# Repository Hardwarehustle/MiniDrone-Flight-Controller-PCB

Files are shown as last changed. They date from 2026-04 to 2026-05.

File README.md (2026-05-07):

#  MiniDrone Flight Controller PCB
## Project Overview

This is a fully integrated **mini quadcopter flight controller PCB** shaped as a drone frame — the PCB itself acts as the structural frame with four motor mount arms extending from the central compute hub. It packs an **ESP32-S3** SoC (dual-core 240 MHz Xtensa LX7, Wi-Fi + BLE 5.0), an **OV2640 camera** (24-pin FPC), a **MPU-6050 IMU** (6-axis gyro + accelerometer), **LiPo battery management** (TP4056 + DW01A + FS8205A), **4× SI2302A N-MOSFET brushed motor drives**, a **microSD card** slot for SD_MMC, and **USB-C OTG** — all on a single X-shaped blue PCB.

The board is designed for a compact indoor FPV or autonomous mini-drone platform with onboard vision, motion sensing, Wi-Fi/BLE telemetry, and local SD logging.

---

##  Project Visuals

### Schematic
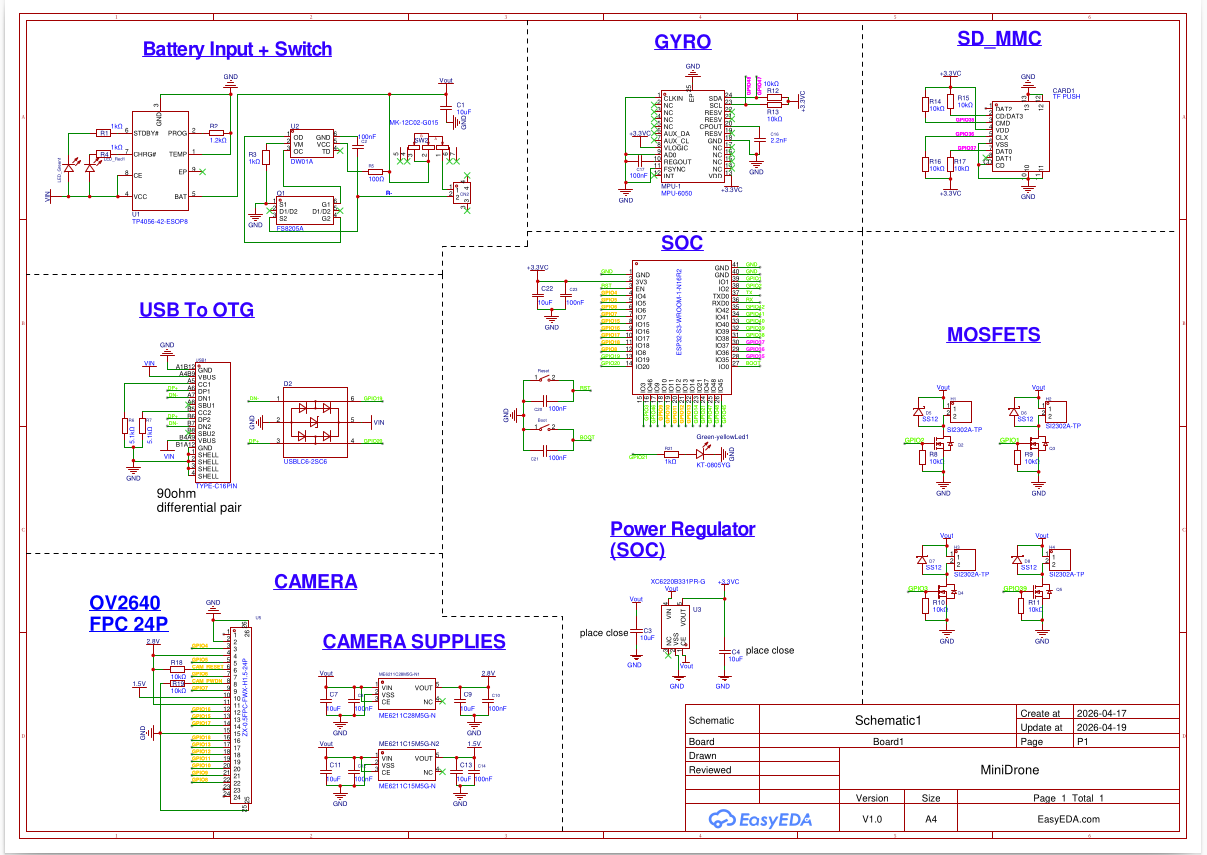
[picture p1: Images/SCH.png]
Schematic


### PCB Layout
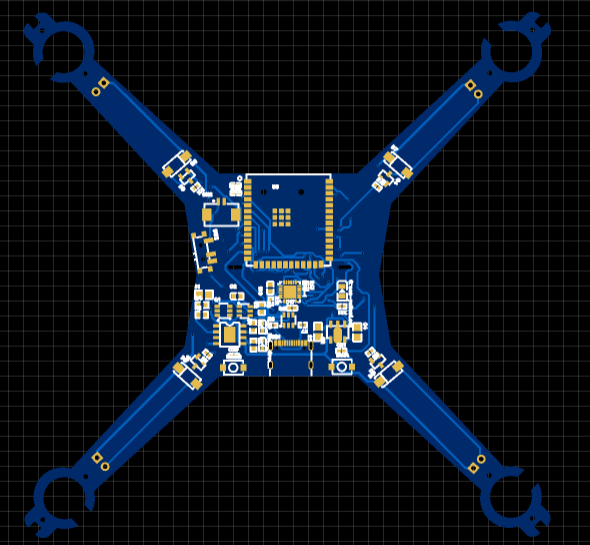
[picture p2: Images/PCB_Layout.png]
PCB Layout


### 3D Board Top View
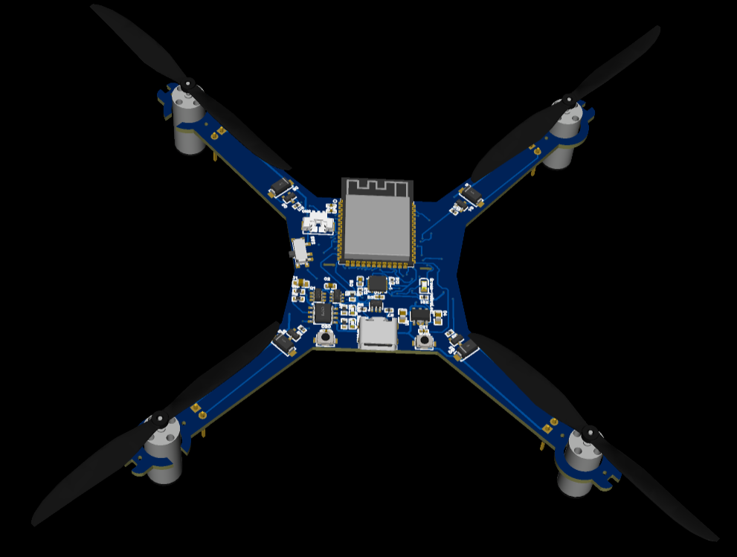
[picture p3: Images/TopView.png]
3D Top View


### 3D Board Bottom View
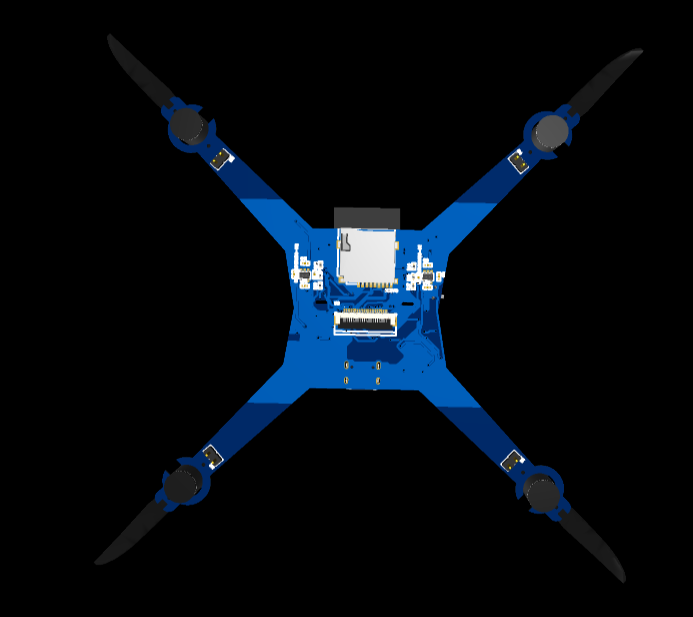
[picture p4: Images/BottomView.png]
3D Bottom View

---

##  System Architecture

```
LiPo Battery ──► MK-12C02 Slide Switch (SW2)
                          │
               TP4056 (U1) Li-ion Charger ◄── USB-C VBUS (charging)
                          │
               DW01A (U2) Battery Protection (OC, OD, TD)
                          │
               FS8205A (Q1) Dual P-MOSFET Protection Switch
                          │
                       Vout Rail
                          │
          ┌───────────────┼───────────────────────────┐
          ▼               ▼                           ▼
  XC6220B331 LDO    ME6211C28 LDO (2.8V)   ME6211C15 LDO (1.5V)
  (+3.3V for SoC)   (OV2640 DVDD/AVDD)     (OV2640 core)
          │
       +3.3VC Rail
          │
   ┌──────┼──────────────────────────────────────┐
   ▼      ▼              ▼           ▼           ▼
ESP32-S3  MPU-6050     SD_MMC     USB-C OTG   SI2302A×4
(SoC)   (Gyro/Accel)  (CARD1)   (TYPE-C16P)  (Motors H1-H4)
   │
   └──► OV2640 Camera (24P FPC, U5)
```

---

##  Component BOM

### Core ICs

| Ref | Part | Function |
|:---:|:---|:---|
| ESP32-S3-WROOM-1-N16R2 | ESP32-S3 SoC | Dual-core 240 MHz, Wi-Fi + BLE 5.0, 16MB Flash, 2MB PSRAM |
| U1 | TP4056-42-ESOP8 | 1A Li-ion/LiPo battery charger |
| U2 | DW01A | Battery protection IC (OC / OD / short circuit) |
| Q1 | FS8205A | Dual N-MOSFET battery protection switch |
| U3 | XC6220B331PR-G | 300mA LDO regulator — Vout → +3.3V |
| ME6211C28M5G-N1 | ME6211C28 | 300mA LDO — 2.8V for OV2640 |
| ME6211C15M5G-N2 | ME6211C15 | 300mA LDO — 1.5V for OV2640 core |
| MPU-1 | MPU-6050 | 6-axis IMU (3-axis gyro + 3-axis accel), I2C |
| U5 | ZX-0.5FPC-FWX-H1.5-24P | OV2640 camera 24-pin FPC connector |
| CARD1 | TF PUSH | MicroSD card (SD_MMC 4-bit interface) |
| USB1 | TYPE-C 16PIN | USB-C OTG connector |
| D2 | USBLC6-2SC6 | USB ESD protection TVS |

### Motor Drive MOSFETs

| Ref | Part | GPIO | Motor |
|:---:|:---:|:---:|:---:|
| Q2 | SI2302A-TP | GPIO2 | Motor H1 (Front-Left) |
| Q3 | SI2302A-TP | GPIO1 | Motor H2 (Front-Right) |
| Q4 | SI2302A-TP | GPIO3 | Motor H3 (Rear-Left) |
| Q5 | SI2302A-TP | GPIO39 | Motor H4 (Rear-Right) |

Each SI2302A N-MOSFET gate is driven directly from ESP32-S3 PWM GPIO through a 10kΩ gate resistor, and is protected by an SS12 Schottky flyback diode (D5–D8).

---

##  ESP32-S3 GPIO Assignment

| GPIO | Signal | Block |
|:---:|:---|:---|
| GPIO1 | Motor H2 (PWM) | MOSFET Q3 |
| GPIO2 | Motor H1 (PWM) | MOSFET Q2 |
| GPIO3 | Motor H3 (PWM) | MOSFET Q4 |
| GPIO39 | Motor H4 (PWM) | MOSFET Q5 |
| GPIO4 | CAM_XCLK | OV2640 Clock |
| GPIO5 | CAM_VSYNC | OV2640 |
| GPIO6 | CAM_RESET | OV2640 |
| GPIO7 | CAM_PWDN | OV2640 Power Down |
| GPIO8–GPIO18 | CAM_D0–D7, PCLK, HREF, SIOC, SIOD | OV2640 data + I2C |
| GPIO19 | USB D+ | USB OTG |
| GPIO20 | USB D− | USB OTG |
| GPIO21 | Status LED | Green-yellow LED |
| GPIO35 | SD_CMD | SD_MMC |
| GPIO36 | SD_CLK | SD_MMC |
| GPIO37 | SD_DAT0 | SD_MMC |
| GPIO47 | MPU-6050 SCL | I2C |
| GPIO48 | MPU-6050 SDA | I2C |
| GPIO0 | BOOT | Boot mode select |
| EN | RESET | Hardware reset |

---

##  Battery Management System

The BMS consists of three stages working together to safely charge and discharge the LiPo cell:

### Stage 1 — Charging: TP4056
- Max charge current: **1A** (set by PROG pin resistor R2 = 1.2kΩ)
- Charge voltage: **4.2V** (fixed internal reference)
- Charging via USB-C VBUS
- CHRG# pin drives **LED_Red** (charging indicator)
- STDBY# pin drives **LED_Green** (charge complete)

### Stage 2 — Protection: DW01A
- Overcurrent protection (OC)
- Over-discharge protection (OD): cuts off battery below ~2.4V
- Short circuit protection (TD)
- Operates with external dual MOSFET (FS8205A)

### Stage 3 — Switching: FS8205A
- Dual N-channel MOSFET in a single SOT-23-6 package
- G1 controlled by OD pin of DW01A
- G2 controlled by OC pin of DW01A
- Both protect battery from damage during abnormal conditions

---

##  OV2640 Camera Interface

The OV2640 is a 2MP image sensor from OmniVision, connected via a **24-pin 0.5mm pitch FPC connector** (ZX-0.5FPC-FWX-H1.5-24P, U5). It requires three regulated power supplies generated by dedicated ME6211 LDOs:

| Rail | Voltage | LDO | Purpose |
|:---:|:---:|:---:|:---|
| AVDD / DOVDD | 2.8V | ME6211C28M5G-N1 | Analog + I/O power |
| DVDD | 1.5V | ME6211C15M5G-N2 | Digital core power |

Camera control pins from ESP32-S3:
- **CAM_RESET** (GPIO6) — hardware reset
- **CAM_PWDN** (GPIO7) — power down mode
- **SIOC/SIOD** — I2C configuration bus (SCCB protocol)
- **GPIO4–GPIO18** — parallel DVP data bus (D0–D7, PCLK, VSYNC, HREF)

---

##  MPU-6050 IMU (Gyro + Accel)

The **MPU-6050** is a 6-axis MEMS IMU providing 3-axis gyroscope and 3-axis accelerometer data over I2C at up to 400 kHz. It is connected to:
- **SDA → GPIO48**, **SCL → GPIO47**
- I2C pull-ups R12 and R13 (10kΩ each) to +3.3VC
- INT pin available for interrupt-driven data-ready notification
- FSYNC pin available for frame sync with camera
- Decoupling: C16 (2.2nF) + C17 (100nF) on VDD

The MPU-6050 data feeds the flight stabilization loop running on the ESP32-S3 for attitude control (roll, pitch, yaw).

---

##  MicroSD Card (SD_MMC)

The microSD card (CARD1 — TF PUSH type) operates in **SD_MMC 4-bit wide bus mode** for high-speed data logging:

| Signal | GPIO | Description |
|:---:|:---:|:---|
| SD_CMD | GPIO35 | Command line |
| SD_CLK | GPIO36 | Clock |
| SD_DAT0 | GPIO37 | Data bit 0 |

Pull-up resistors R14–R17 (10kΩ) hold all SD_MMC lines high when idle.

---

##  USB-C OTG

The **TYPE-C 16-pin connector** (USB1) supports:
- **USB 2.0 Full-Speed** native on ESP32-S3 (GPIO19/GPIO20 as D+/D−, 90Ω differential pair)
- **OTG** capability — can act as USB device or host
- CC1/CC2 lines with R6/R7 (5.1kΩ) for USB-C cable orientation and current advertisement
- **USBLC6-2SC6 TVS array (D2)** for full ESD protection on DP/DM lines
- VBUS routing for charging input to TP4056

---

##  Auto-Reset and Boot Circuit

| Signal | GPIO | Component | Function |
|:---:|:---:|:---:|:---|
| RST | EN | C20 (100nF) | Reset filter capacitor |
| BOOT | GPIO0 | C21 (100nF) | Boot mode filter cap |
| RST | — | RESET button | Manual reset |
| BOOT | — | BOOT button | Manual boot mode entry |
| GPIO21 | — | Green-yellow LED (KT-0805YG) + R21 1kΩ | Status indicator |

---

##  Power Architecture Summary

```
USB-C VBUS (5V) ──► TP4056 charger ──► LiPo Battery (3.7V)
                                              │
                                        DW01A + FS8205A
                                              │
                                           Vout
                          ┌───────────────────┼────────────────────┐
                          ▼                   ▼                    ▼
                  XC6220B331 LDO       ME6211C28 (2.8V)    ME6211C15 (1.5V)
                   → +3.3V              → OV2640 AVDD         → OV2640 DVDD
                   ESP32-S3
                   MPU-6050
                   SD Card
                          │
                  4× SI2302A → Brushed Motors (direct Vout)
```

---

##  PCB Design Highlights

- **Tool:** EasyEDA V1.0
- **Board shape:** X-frame quadcopter — PCB is simultaneously the structural drone frame
- **Arm ends:** 4× motor mount clamps (H1–H4) at arm tips
- **Center hub:** ESP32-S3, camera FPC, MPU-6050, SD card, USB-C all centrally placed
- **Color:** Blue PCB with gold pads (ENIG finish recommended)
- **Layers:** 2-layer
- **USB differential pair:** Routed as 90Ω controlled impedance

---

##  Bring-Up Procedure

### Step 1 — Power Check
- Connect LiPo battery and slide SW2 to ON
- Measure Vout (3.5–4.2V), +3.3V at ESP32 VDD, 2.8V at OV2640, 1.5V at OV2640 DVDD

### Step 2 — USB and Programming
- Connect USB-C to PC
- Press BOOT + RESET (or use auto-reset via DTR/RTS if host-side bridge added)
- Flash firmware using ESP-IDF or Arduino IDE (ESP32-S3 target)

### Step 3 — IMU Test
- I2C scan on GPIO47/GPIO48 — expect MPU-6050 at address 0x68
- Read accel and gyro registers — verify non-zero output when board is tilted

### Step 4 — Camera Test
- Enable OV2640 power (ME6211 CE pins asserted)
- Init SCCB (I2C) to configure OV2640 registers
- Read a JPEG frame — verify image over Wi-Fi or SD

### Step 5 — SD Card Test
- Mount FAT32 SD card
- Write a test log file — verify read-back

### Step 6 — Motor Test
- Apply PWM to GPIO1–GPIO3 and GPIO39 at low duty (5–10%)
- Verify each SI2302A gate toggles correctly with oscilloscope
- Verify motor spins at low throttle safely

---

##  Design Notes & Cautions

- **SI2302A gate voltage** — ESP32-S3 GPIO drives 3.3V; SI2302A Vgs(th) ≈ 0.9V min, ensure full enhancement at 3.3V drive
- **SS12 flyback diodes (D5–D8)** — essential for brushed motor inductive kickback protection; place close to MOSFET drain
- **OV2640 power sequence** — apply 2.8V before 1.5V per OV2640 datasheet power-up sequence
- **90Ω USB differential pair** — GPIO19/GPIO20 traces must be routed as a matched-impedance differential pair; keep equal length and spacing
- **MPU-6050 placement** — mount at the board center of mass for accurate attitude measurement; avoid placing near switching regulators
- **TP4056 PROG resistor (R2 = 1.2kΩ)** — sets charge current to ~1A; verify LiPo cell can handle this charge rate (1C minimum rated capacity)
- **PCB-as-frame structural note** — board is structural; use FR4 1.6mm minimum thickness; motor clamp holes should be reinforced with copper rings

---

## License

This project is open for educational and personal use.  
© 2026 Janardhan BV — All rights reserved.

---

## Author

**Janardhan BV**  
Embedded Hardware Engineer | PCB Design | Robotics  
Bengaluru, India

---
*MiniDrone — ESP32-S3 Flight Controller PCB | Designed in EasyEDA*

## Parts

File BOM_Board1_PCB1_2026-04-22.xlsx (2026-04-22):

No. | Quantity | Comment | Designator | Footprint | Value | Manufacturer Part | Manufacturer | Supplier Part | Supplier
1 | 2 | TS-1088R-02026 | Boot,Reset | SW-SMD_L3.9-W3.0-P4.45 |  | TS-1088R-02026 | XUNPU(讯普) | C455280 | LCSC
2 | 3 | 10uF | C1,C3,C4 | C0805 | 10uF | CL10A106MQ8NNNC | SAMSUNG(三星) | C1691 | LCSC
3 | 1 | 100nF | C2 | C0603 | 100nF | 0603B104K250CT | Walsin(华新科) | C83054 | LCSC
4 | 5 | 10uF | C7,C9,C11,C13,C22 | C0402 | 10uF | CL10A106MQ8NNNC | SAMSUNG(三星) | C1691 | LCSC
5 | 8 | 100nF | C8,C10,C12,C14,C17,C20,C21,C23 | C0402 | 100nF | CC0402KRX7R7BB104 | YAGEO(国巨) | C60474 | LCSC
6 | 1 | 2.2nF | C16 | C0603 | 2.2nF | 0603B222K500CT | Walsin(华新科) | C93190 | LCSC
7 | 1 | TF PUSH | CARD1 | TF-SMD_TF-PUSH |  | TF PUSH | SHOU HAN(首韩) | C393941 | LCSC
8 | 1 | AFC12-S02DCC-00 | CN2 | CONN-SMD_AFC12-S02DCC-00 |  | AFC12-S02DCC-00 | JS(钜硕电子) | C395328 | LCSC
9 | 1 | USBLC6-2SC6 | D2 | SOT-23-6_L2.9-W1.6-P0.95-LS2.8-BL |  | USBLC6-2SC6 | ST(意法半导体) | C7519 | LCSC
10 | 4 | SS12 | D5,D6,D7,D8 | SMA_L4.4-W2.8-LS5.4-RD |  | SS12 | LGE(鲁光) | C432149 | LCSC
11 | 1 | KT-0805YG | Green-yellowLed1 | LED0805-R-RD |  | KT-0805YG | KENTO | C2292 | LCSC
12 | 4 | B-2100S02P-A110 | H1,H2,H3,H4 | HDR-TH_2P-P2.54-V-M-1 |  | B-2100S02P-A110 | Ckmtw(灿科盟) | C124375 | LCSC
13 | 1 | LTST-C193TGKT-5A | LED_Green1 | LED0603-RD |  | LTST-C193TGKT-5A | LITEON(光宝) | C12065 | LCSC
14 | 1 | LTST-C191KRKT | LED_Red1 | LED0603-RD |  | LTST-C191KRKT | LITEON(光宝) | C125099 | LCSC
15 | 4 | 8520 motor | M3,M3,M3,M3 | 8520 coreless motor
16 | 1 | ME6211C15M5G-N | ME6211C15M5G-N2 | SOT-23-5_L3.0-W1.7-P0.95-LS2.8-BR |  | ME6211C15M5G-N | MICRONE(南京微盟) | C53100 | LCSC
17 | 1 | ME6211C28M5G-N | ME6211C28M5G-N1 | SOT-23-5_L3.0-W1.7-P0.95-LS2.8-BR |  | ME6211C28M5G-N | MICRONE(南京微盟) | C53099 | LCSC
18 | 1 | MPU-6050 | MPU-1 | QFN-24_L4.0-W4.0-P0.50-BL-EP2.7 |  | MPU-6050 | TDK InvenSense(应美盛) | C24112 | LCSC
19 | 1 | FS8205A | Q1 | SOT-23-6_L2.9-W1.6-P0.95-LS2.8-BR |  | FS8205A | FUXINSEMI(富芯森美) | C908265 | LCSC
20 | 4 | SI2302A-TP | Q2,Q3,Q4,Q5 | SOT-23-3_L2.9-W1.3-P1.90-LS2.4-BR |  | SI2302A-TP | MCC(美微科) | C668996 | LCSC
21 | 3 | 1kΩ | R1,R3,R4 | R0603 | 1kΩ | AR03BTCX1001 | Viking(光颉) | C304069 | LCSC
22 | 1 | 1.2kΩ | R2 | R0603 | 1.2kΩ | RC0603JR-071K2L | YAGEO(国巨) | C114679 | LCSC
23 | 1 | 100Ω | R5 | R0603 | 100Ω | 0603WAJ0101T5E | UNI-ROYAL(厚声) | C25201 | LCSC
24 | 2 | 5.1kΩ | R6,R7 | R0402 | 5.1kΩ | 0402WGF5101TCE | UNI-ROYAL(厚声) | C25905 | LCSC
25 | 12 | 10kΩ | R8,R9,R10,R11,R12,R13,R14,R15,R16,R17,R18,R19 | R0402 | 10kΩ | RC0402FR-0710KL | YAGEO(国巨) | C60490 | LCSC
26 | 1 | 1kΩ | R21 | R0402 | 1kΩ | 0402WGF1001TCE | UNI-ROYAL(厚声) | C11702 | LCSC
27 | 1 | MK-12C02-G015 | SW2 | SW-SMD_G-SWITCH_MK-12C02-G015 |  | MK-12C02-G015 | G-Switch(品赞) | C2911519 | LCSC
28 | 1 | TP4056-42-ESOP8 | U1 | ESOP-8_L4.9-W3.9-P1.27-LS6.0-BL-EP |  | TP4056-42-ESOP8 | TOPPOWER(南京拓微) | C16581 | LCSC
29 | 1 | DW01A | U2 | SOT-23-6_L2.9-W1.6-P0.95-LS2.8-BL |  | DW01A | PUOLOP(迪浦) | C351410 | LCSC
30 | 1 | XC6220B331PR-G | U3 | SOT-89-5_L4.5-W2.5-P1.50-LS4.4-BR |  | XC6220B331PR-G | TOREX(特瑞仕) | C3013658 | LCSC
31 | 1 | ZX-0.5FPC-FWX-H1.5-24P | U5 | FPC-SMD_24P-P0.50_ZX-0.5FPC-FWX-H1.5-24P |  | ZX-0.5FPC-FWX-H1.5-24P | Megastar(兆星) | C7544628 | LCSC
32 | 1 | ESP32-S3-WROOM-1-N16R2 | U9 | WIRELM-SMD_ESP32-S3-WROOM-1 |  | ESP32-S3-WROOM-1-N16R2 | ESPRESSIF(乐鑫) | C2913205 | LCSC
33 | 1 | TYPE-C16PIN | USB1 | USB-C-SMD_TYPE-C16PIN |  | TYPE-C16PIN | SHOU HAN(首韩) | C393939 | LCSC

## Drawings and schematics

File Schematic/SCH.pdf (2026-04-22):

# Battery Input + Switch

# GYRO

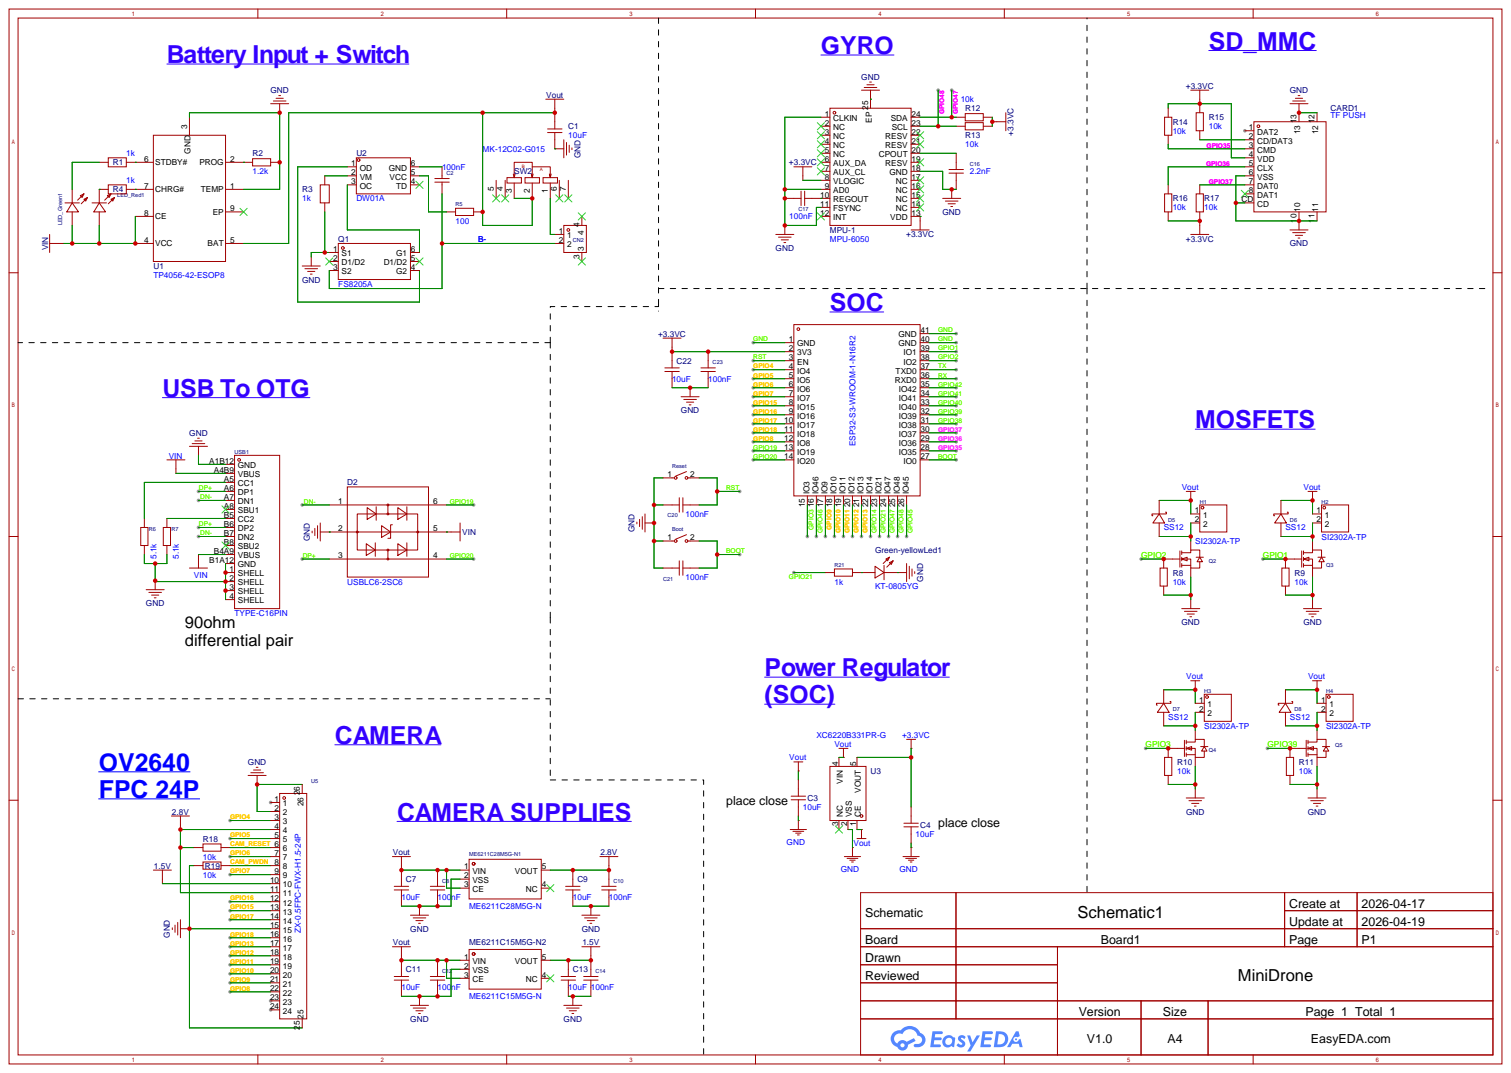
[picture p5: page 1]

IO0 27 IO⁴⁵ 26 IO⁴⁸ 25 IO⁴⁷ 24 IO²¹ 23 IO¹⁴ 22 IO¹³ 21 IO¹² 20 IO¹¹ 19 IO¹⁰ 18 IO⁹ 17 IO⁴⁶ 16 IO³ 15

Schematic | Schematic1 | Create at | 2026-04-17

Update at | 2026-04-19

Drawn | MiniDrone
Reviewed

Version | Size | Page 1 Total 1
V1.0 | A4 | EasyEDA.com

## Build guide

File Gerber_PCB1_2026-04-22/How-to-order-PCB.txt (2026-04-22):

How to Order PCB

Please refer to:
https://prodocs.easyeda.com/en/pcb/order-order-pcb/index.html
